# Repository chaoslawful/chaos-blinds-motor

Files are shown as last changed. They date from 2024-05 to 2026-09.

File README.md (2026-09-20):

# Chaos Blinds Motor

English | [中文](README-zh.md)

## Introduction

This project implements a blinds motor based on ESP8266 MCU, allowing users to manually control the blinds opening and closing using a universal infrared remote control or remotely via the HomeAssistant gateway. Compared to existing products on the market, this project has the following benefits:

* Low cost: The total cost of components plus the 3D-printed casing is less than 50 RMB, which is 1/4 to 1/5 of the price of commercial products.

* Completely open: The circuit, code, and casing models are all open source, and components can be purchased on the market. Users can freely modify and add new functions.

* Educational: The structure is simple, suitable for hands-on DIY activities with children.

## Hardware Structure

Component list:

* **Main control board**: `NodeMCU Lolin V3` (or other development boards of the same size with pin function compatibility)

* **Motor driver**: `DRV8833` module

* **Infrared receiver**: `HX1838`

* **DC motor**: Single-axis worm gear reduction motor with Hall encoder (preferably with metal gears)

The wiring diagram is as follows:

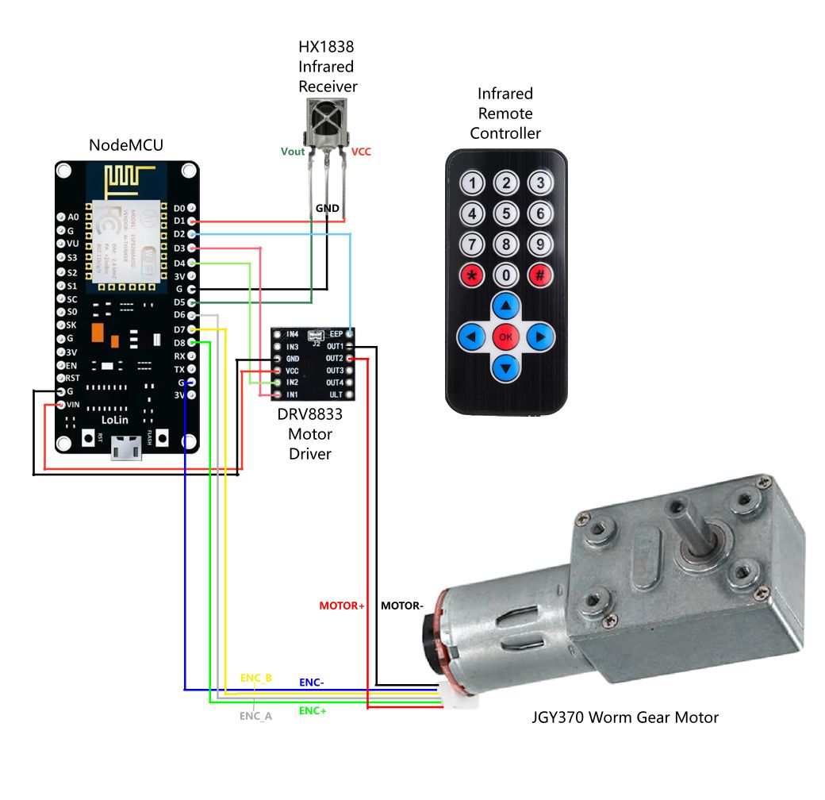
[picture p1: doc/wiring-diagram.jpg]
Wiring Diagram


## Firmware Compilation and Upload

The firmware is now the ESPHome reimplementation in `esphome/` (the legacy Arduino implementation has been removed from the working tree; see the git history if you need it). Refer to `esphome/README.md` for build, first-flash and OTA instructions.

## Make outer casing

When using FDM 3D printing, consider the following slicing parameters:

* Layer height: 0.12mm

* Number of walls: 6

* Sparse infill density: 25%

### Ball Chain Pulley

Open the [](./cad/ball-chain-pulley.step) file in your slicing software, split it into objects, and automatically arrange them for printing. Finally, use 4 **M3x12** screws to fix the upper and lower halves of the pulley together. If you need to add spacers, use 4 **M3x16** screws to fix the upper and lower halves of the pulley and the spacers together.

The reference layout in the slicing software is as follows:

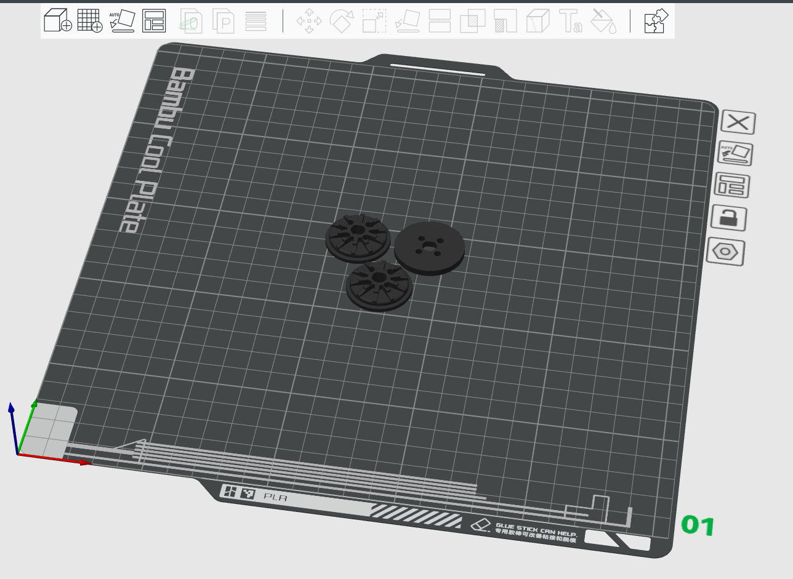
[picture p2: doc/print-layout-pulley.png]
Reference layout for pulley


#### Blinds Motor Casing

Open the [](./cad/chaos-blinds-motor.step) file in your slicing software, split it into objects, and automatically arrange them for printing. Note that the locking pieces should be placed sideways and add a **5mm brim** to stabilize printing. After printing, glue the locking pieces and sliders together with glue to form a complete back plate fixing piece.

The reference layout in the slicing software is as follows:

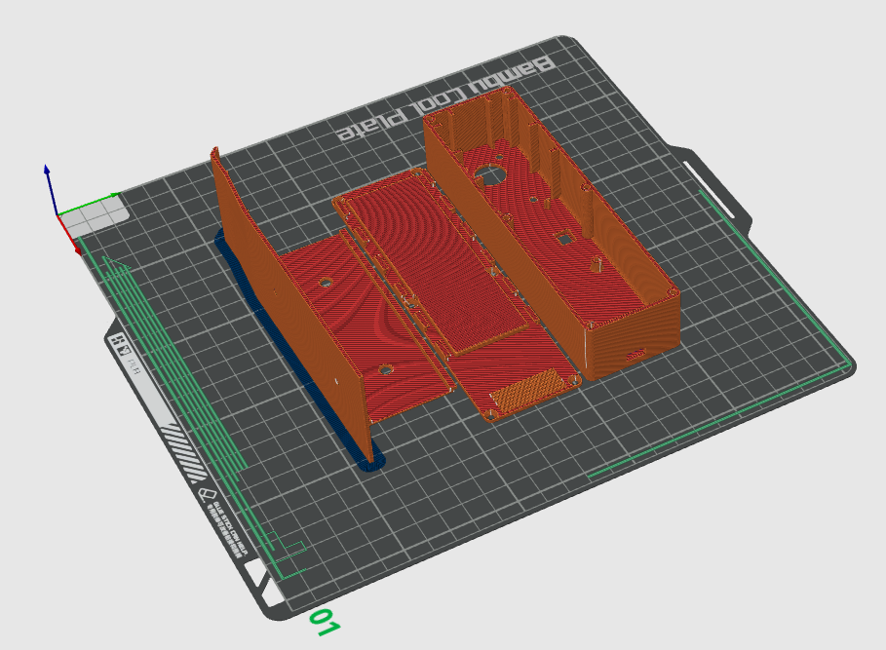
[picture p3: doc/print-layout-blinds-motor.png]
Reference layout for blinds motor


## Assembly

1. Before assembly, connect various components with DuPont wires according to the wiring diagram. Test the functionality before disassembling and continuing with the assembly.

2. Secure the NodeMCU board with 4 **M3x4** countersunk self-tapping screws, with the back facing up, inside the casing. The MicroUSB port should fit into the rectangular opening at the bottom.

3. Use hot glue to secure the DRV8833 module to the back of the NodeMCU near the MicroUSB port.

4. Use 4 **M3x6** countersunk screws to secure the reduction motor to the casing.

5. Connect various components with DuPont wires according to the wiring diagram and bundle them with plastic zip ties, making sure not to obstruct the rotation of the magnet ring of the Hall encoder.

6. Use 4 **M3x12** countersunk self-tapping screws to secure the back plate to the casing.

7. Install the ball chain pulley onto the motor shaft and hang the blinds ball chain. Find the appropriate installation position and angle to ensure that the chain is tensioned without entanglement and the blinds motor can slide freely into and out of the back plate fixing piece. Mark the appropriate position and angle.

8. Secure the back plate fixing piece at the marked position using expansion screws or 3M double-sided tape. Slip the ball chain onto the blinds motor pulley and insert the blinds motor into the back plate fixing piece.

9. Connect a **5~7.2V** external DC power supply to the MicroUSB port. The higher the voltage, the faster the blinds will rise and fall.

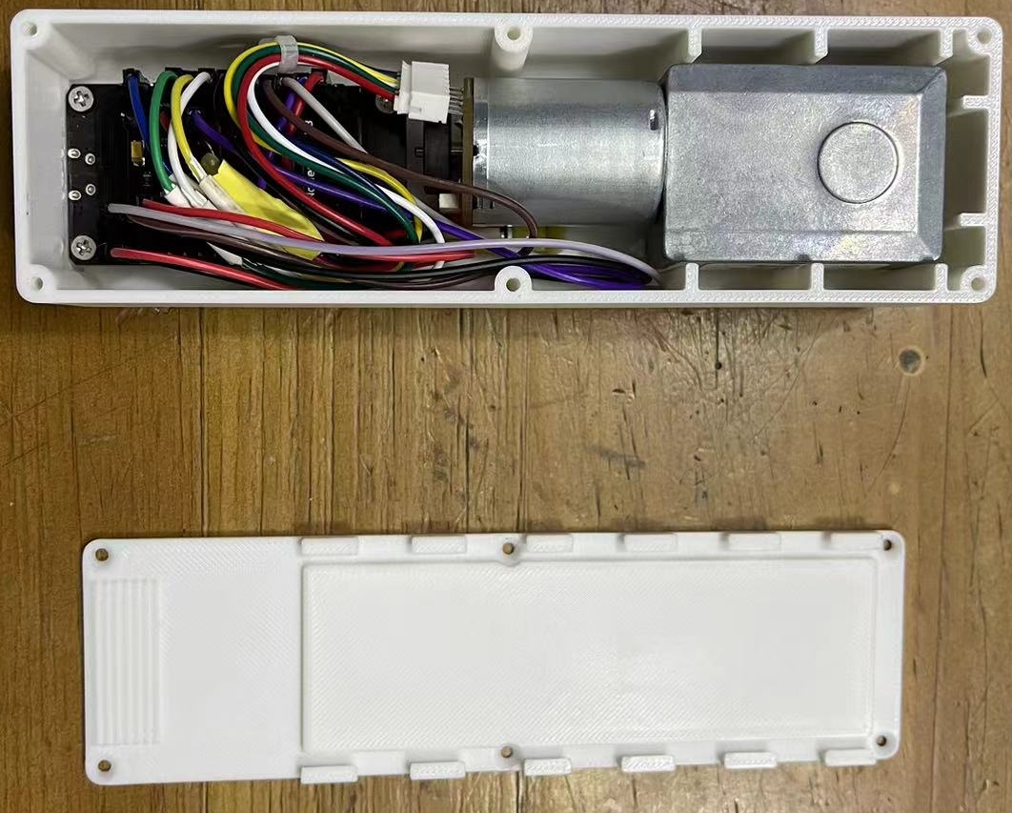
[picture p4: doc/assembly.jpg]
Assembly reference


## Configuration and Usage

1. **Network Configuration**: After the first power-up, wait for 5 seconds. Search for the hotspot named `ESP-xxxxxx` on your phone and connect to it. The wireless and MQTT configuration interface will automatically pop up. Fill in the wireless SSID and password, MQTT service address, port, login username, and password, and then save and close. At this point, the blinds motor will automatically connect to your wireless hotspot and the corresponding HomeAssistant (HA) service.

   * The MQTT-related parameters depend on your HA service configuration. Please search online for how to configure the HA service in the local network and allow external devices to access the HA service through MQTT.

2. **Travel Calibration**: The left and right buttons on the remote control can forcibly control the motor movement. Normally, the left button raises and the right button lowers the blinds. Press the `OK` button to stop the motor. If the movement direction is reversed, sequentially press the `0` and `#` buttons on the remote control to set the motor to reverse movement. Control the motor to move the blinds to the fully open position. Press the `0` and `1` buttons sequentially to save the fully open position. Then move the blinds to the fully closed position. Press the `0` and `3` buttons sequentially to save the fully closed position. The travel calibration is now complete. If necessary, press the `0` and `2` buttons sequentially to clear the calibrated travel and reset the current motor position to the initial position.

3. **Usage**:
   * Remote control up button: Fully open the blinds.
   * Remote control down button: Fully close the blinds.
   * Remote control `OK` button: Stop the motor.
   * After successfully connecting to the HA service, you can control it through the web or mobile app in the same way. You can also use automation rules in HA for scheduled blinds opening and closing.

## Acknowledgments

* [Parametric pulley generator for Aqara roller shade driver e1 by 2by2 - Thingiverse](https://www.thingiverse.com/thing:6116520)

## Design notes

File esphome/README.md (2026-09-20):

# 混沌猫升窗器 · ESPHome 版

原 Arduino 版（已从本仓库移除，历史提交中仍可查阅）的 ESPHome 重构实现，功能完全对齐，基础设施（WiFi/OTA/日志/持久化/看门狗）全部由 ESPHome 托管。

## 目录结构

```
esphome/
├─ chaos-blinds-motor.yaml    # 主配置（引脚/WiFi/API/OTA/红外状态机/HA 实体）
├─ secrets.yaml               # 凭据（首次使用前填写）
└─ components/
   └─ motor_pid/              # 自写外部组件：位置闭环 PID 电机 Cover
      ├─ __init__.py          # ESPHome 代码生成与配置校验
      ├─ motor_pid.h
      └─ motor_pid.cpp        # 控制环（移植自原版 MotorService）
```

## 快速开始

```bash
pip install esphome
cd esphome

# 1. 填写 secrets.yaml（api_encryption_key 用 openssl rand -base64 32 生成）

# 2. 校验配置
esphome config chaos-blinds-motor.yaml

# 3. 烧录（二选一，见下）
esphome run chaos-blinds-motor.yaml
```

### 首次烧录方式

**方式 A：免拆机 OTA 迁移（推荐，设备仍在运行旧 Arduino 固件时）**

ESPHome 的 OTA 与旧固件的 ArduinoOTA 使用同一协议（ESP8266 TCP 8266 端口），可直接无线推送，无需 USB：

1. 先把 `secrets.yaml` 的 `ota_password` 填为 `chaos123456`（**必须与旧固件当前密码一致**，OTA 校验的是设备上正在运行的固件的密码）；
2. 指定设备 IP 推送（旧固件 mDNS 主机名与新版不同，不要依赖自动发现）：

```bash
esphome run chaos-blinds-motor.yaml --device <设备IP>
```

3. 首次刷入成功后，之后的 OTA 密码以 `secrets.yaml` 为准，可改新密码。

**方式 B：USB 烧录**

`esphome run chaos-blinds-motor.yaml` 即可（自动检测串口）。

烧录前建议先用 `esptool.py read_flash` 备份原版固件，以便随时回退（Arduino 版仓库保留即可）。

## 标定流程（与原版一致）

红外遥控器操作（所有标定键需先按 `0` 且电机位置不动）：

| 按键 | 功能 |
|---|---|
| ← / → | 手动升起 / 放下（全速） |
| OK | 停止 |
| ↑ / ↓ | 自动运行至全开 / 全关 |
| 0,1 | 标定当前位置为全开点 |
| 0,3 | 标定当前位置为全关点 |
| 0,2 | 清除标定并归零编码器 |
| 0,# | 切换电机转向 |
| 0,4 | 手动对时（本版 SNTP 自动对时，此键仅打日志） |

Home Assistant 侧提供等价能力：原生 **Cover 实体**（开/关/停/任意位置百分比 + 位置反馈）、标定按钮三个、手动点动按钮三个（Jog Open / Jog Close / Jog Stop，与红外 ← → OK 等价，全速运转直到判稳停、60s 硬超时或手动停止）、转向反转开关、WiFi 信号/运行时长传感器。

## 与原版差异（有意为之的改动）

| 项 | 原版 | 本版 | 原因 |
|----|---|---|---|
| HA 通道 | MQTT + ArduinoHA 三按钮 | 原生 API（加密）+ Cover 实体 | 修复凭据泄露（R1），体验升级 |
| 清 WiFi 配 | RESET 后按 FLASH 键（占用 D3） | 回退 AP + captive_portal | 修复 D3 引脚冲突（R3） |
| 配置持久化 | LittleFS 裸 JSON 写 | ESPHome preferences（原子 + CRC） | 修复掉电丢标定（R4） |
| 运动超时 | 无 | `max_run_time` 默认 60s 硬停机 | 新增失控兜底（R5） |
| 手动停止后 | 不保存位置 | 保存位置 | 更稳妥 |
| PWM 频率 | 128Hz（可闻啸叫） | 默认 20kHz（YAML 可改回） | 体验改进（R14） |
| 主频 | 160MHz 超频 | 80MHz | ESPHome 不支持该配置；5ms 环裕量充足 |
| Web 日志 | 8080 无鉴权、含明文密码 | 80 端口带鉴权 | 安全 |
| 电池电压 | pins.h 预留死代码 | 不移植（A0 无分压电路，无实际用途） | 用户确认移除 |

## PID 调试

固件已编译进 VERBOSE 级日志（`logger.level: VERBOSE` + `initial_level: INFO`），日常运行零开销。调试时无需改配置、无需重刷：

- **Web 控制台**：日志级别下拉框切到 `VERBOSE`；
- 或 `logger.set_level` 动作 / `esphome logs` 切换。

随即输出 Teleplot 格式的 `>pos:` / `>speed:` / `>pwm:` 数据流，与原版串口调试方式一致；调完切回 `INFO` 即可。

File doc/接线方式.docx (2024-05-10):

#### 接线方式

HX1838: VCC ---- NodeMCU: D1

HX1838: GND ---- NodeMCU: 紧挨着 D5 的 GND

HX1838: VOUT ---- NodeMCU: D5

DRV8833: EEP ---- NodeMCU: D2

DRV8833: IN1 ---- NodeMCU: D3

DRV8833: IN2 ---- NodeMCU: D4

DRV8833: VCC ---- NodeMCU: Vin

DRV8833: GND ---- NodeMCU: 紧挨着Vin的GND

DRV8833: OUT1 ---- 减速电机: MOTOR-（黑）

DRV8833: OUT2 ---- 减速电机: MOTOR+（红）

减速电机: ENC_A（白）---- NodeMCU: D6

减速电机: ENC_B（黄）---- NodeMCU: D7

减速电机: ENC+（绿）---- NodeMCU: D8

减速电机: ENC-（蓝）---- NodeMCU: 紧挨着3.3V的GND

#### HX1838 引脚图

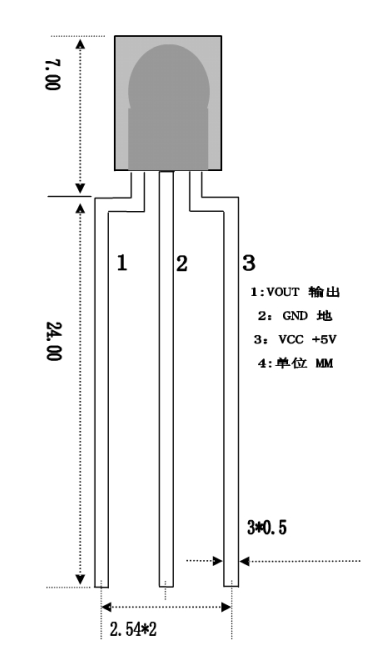
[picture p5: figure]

#### DRV8833 引脚图

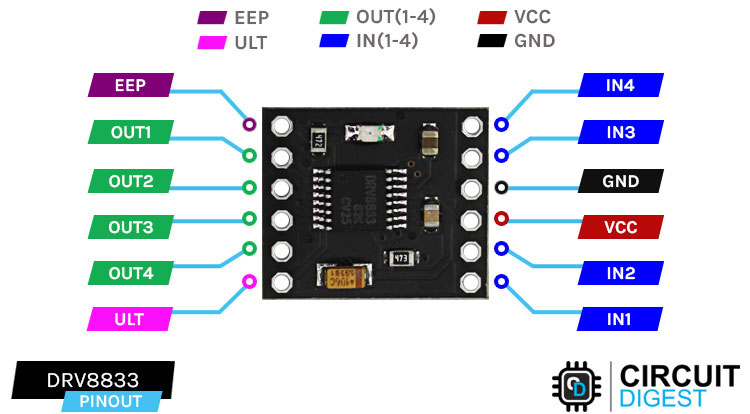
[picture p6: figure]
Interfacing DRV8833 Dual Motor Driver Module with Arduino

#### NodeMCU 引脚图

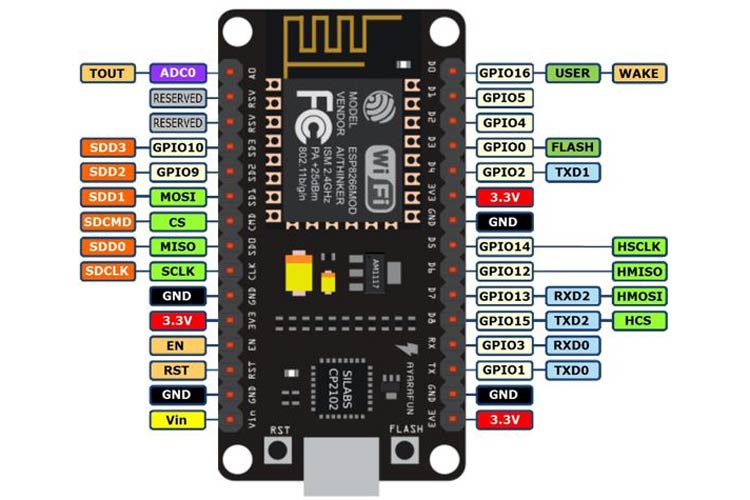
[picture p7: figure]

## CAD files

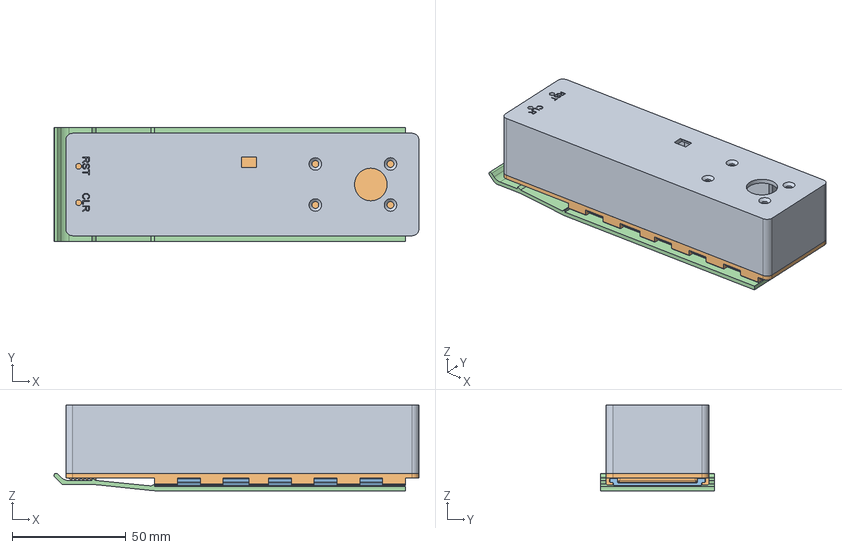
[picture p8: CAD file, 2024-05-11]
cad/chaos-blinds-motor.step
160.2 x 50.0 x 37.6 mm
外壳
外壳滑动背板
滑片
锁紧片

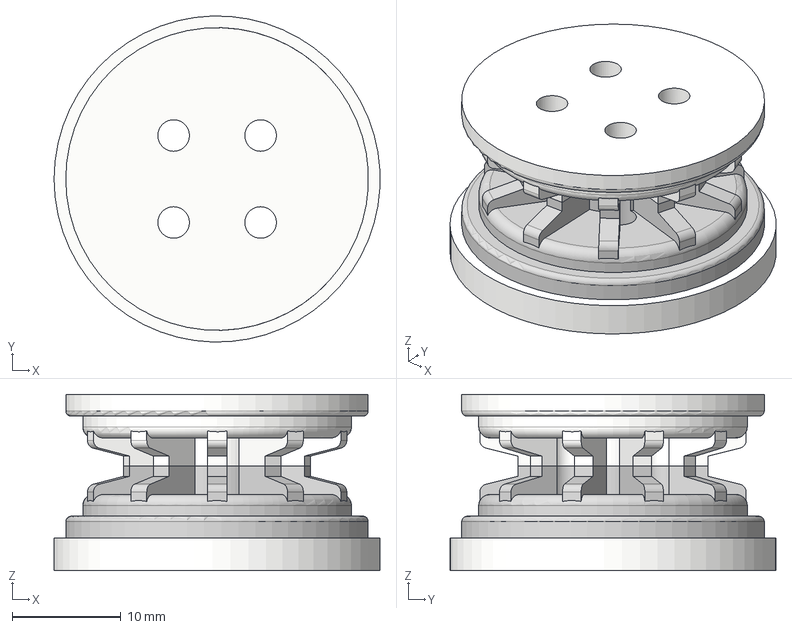
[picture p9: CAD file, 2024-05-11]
cad/ball-chain-pulley.step
30.0 x 30.0 x 16.2 mm
TopHalf
BottomHalf
Spacer

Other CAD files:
cad/ball-chain-pulley.f3d
cad/chaos-blinds-motor.f3d

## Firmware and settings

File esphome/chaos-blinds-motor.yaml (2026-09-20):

# ================================================================
# 混沌猫升窗器 —— ESPHome 重构版
# 目标硬件：NodeMCU Lolin V3 (ESP8266) + DRV8833 + 370 蜗轮减速电机
#           （霍尔编码器 12PPR）+ HX1838 红外接收 + NEC 17 键遥控器
# 功能与 Arduino 版完全对齐，差异详见 README.md「与原版差异」一节
# ================================================================

esphome:
  name: chaos-blinds-motor
  friendly_name: 混沌猫升窗器
  comment: "基于 ESPHome 的百叶窗自动升窗器"
  project:
    name: chaos.blinds_motor
    version: "2.0.0"
  on_boot:
    # 尽早使能编码器与红外接收头电源（对应原版构造函数中的 digitalWrite HIGH）
    priority: 600
    then:
      - lambda: |-
          pinMode(${enc_pwr_pin}, OUTPUT);
          digitalWrite(${enc_pwr_pin}, HIGH);
          pinMode(${ir_pwr_pin}, OUTPUT);
          digitalWrite(${ir_pwr_pin}, HIGH);

# ----------------------------------------------------------------
# 引脚定义（与 src/config/pins.h 一一对应）
# 注意：D3 在原版中被「FLASH 清配按钮」与「电机 IN1」双重占用（缺陷 R3），
#       本版清配功能由 captive_portal 取代，D3 独占电机 PWM。
# ----------------------------------------------------------------
substitutions:
  drv_in1_pin: D3    # DRV8833 输入 1（PWM）
  drv_in2_pin: D4    # DRV8833 输入 2（PWM）
  drv_eep_pin: D2    # DRV8833 使能（高电平工作，低电平休眠）
  enc_a_pin: D6      # 编码器 A 相
  enc_b_pin: D7      # 编码器 B 相
  enc_pwr_pin: D8    # 编码器电源
  ir_pin: D5         # 红外接收数据
  ir_pwr_pin: D1     # 红外接收电源

esp8266:
  board: nodemcuv2
  # 注：原版超频 160MHz 的配置 ESPHome 不支持；80MHz 下 5ms PID 环裕量充足，
  #     实测 loop 耗时远低于采样周期，无功能影响。

# WiFi：失败自动重连；连不上时开启回退 AP + 配网门户（取代 WiFiManager）
wifi:
  ssid: !secret wifi_ssid
  password: !secret wifi_password
  fast_connect: on
  ap:
    ssid: "Blinds-Motor Fallback"
    password: !secret ap_password

captive_portal:

# HA 原生 API（加密；取代原版的 MQTT + ArduinoHA 通道）
api:
  encryption:
    key: !secret api_encryption_key
  reboot_timeout: 5min

# OTA：改用 Noise 加密（继承 api 的 encryption key 认证上传者），
# 替代初始迁移期临时使用的 password（迁移已完成，密码不再需要）
ota:
  - platform: esphome
    encryption:

# 日志：编译期全局级别设为 VERBOSE（把组件内 Teleplot 位置/速度/PWM 调试输出编进固件），
# 但 initial_level 保持 INFO 不影响日常性能；
# 调试 PID 时无需重刷固件，网页控制台下拉框或 logger.set_level 直接切到 VERBOSE 即可
logger:
  level: VERBOSE
  initial_level: INFO
  logs:
    wifi: ERROR
    web_server: ERROR
  baud_rate: 115200

# Web 控制台（带鉴权；取代原版 8080 端口的无鉴权日志页，修复凭据泄露）
web_server:
  port: 80
  auth:
    type: digest
    username: !secret web_user
    password: !secret web_password

# 时间同步：SNTP 非阻塞（取代原版每小时阻塞式 NTP）
time:
  - platform: sntp
    id: ntp_time
    timezone: CST-8
    servers:
      - cn.pool.ntp.org
      - ntp.aliyun.com
    on_time_sync:
      - logger.log: "Time synchronized via SNTP"

# 本地外部组件：位置闭环 PID 电机 Cover
external_components:
  - source:
      type: local
      path: components

# ================================================================
# 电机 Cover（自写组件 motor_pid，HA 中呈现为原生 Cover 实体，
# 支持 open / close / stop / set_position 与位置百分比反馈）
# 注意：必须以 cover 平台方式注册，顶层 motor_pid: 域不会把 cover
# 组件源码加入编译（USE_COVER 已定义但 cover.h 缺失，编译失败）
# ================================================================
cover:
  - platform: motor_pid
    id: motor_cover
    name: "百叶窗"
    in1_pin: ${drv_in1_pin}
    in2_pin: ${drv_in2_pin}
    sleep_pin: ${drv_eep_pin}
    encoder_a_pin: ${enc_a_pin}
    encoder_b_pin: ${enc_b_pin}
    # 控制参数与原版 src/service/motor.h 默认值一致
    kp: 2.0
    ki: 0.2
    kd: 0.12
    sample_time: 5ms
    stable_samples: 20
    stable_window: 50ms
    abs_tolerance: 80.0
    rel_tolerance: 0.01
    max_run_time: 60s        # 新增安全兜底：运动硬超时
    pwm_frequency: 20kHz     # 原版 128Hz 有可闻啸叫；要完全一致可改回 128Hz
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

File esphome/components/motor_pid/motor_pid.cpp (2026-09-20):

#include "motor_pid.h"
#include "esphome/core/log.h"
#include "esphome/core/helpers.h"
#include <cmath>

namespace esphome {
namespace motor_pid {

static const int PWM_RANGE = 255;  // 与原版一致：analogWriteRange(255)

// ------------------------------------------------------------------
// 生命周期
// ------------------------------------------------------------------

void MotorPIDCover::setup() {
  // DRV8833 引脚初始化：默认停机 + 驱动模块休眠（直接操作原始 GPIO，与原版一致）
  pinMode(in1_, OUTPUT);
  pinMode(in2_, OUTPUT);
  pinMode(sleep_, OUTPUT);

  analogWriteRange(PWM_RANGE);
  analogWriteFreq(pwm_freq_);
  analogWrite(in1_, 0);
  analogWrite(in2_, 0);
  digitalWrite(sleep_, LOW);

  // 编码器（PJRC，中断驱动）
  encoder_ = new Encoder(enc_a_, enc_b_);

  // 速度 EMA 滤波系数：α = 1 - e^(-T/τ)，τ = 1/(2π·fc)，T = 10ms（与原版一致）
  float tau = 1.0f / (2.0f * PI * speed_cutoff_hz_);
  speed_alpha_ = 1.0f - expf(-0.010f / tau);

  // 恢复持久化状态（标定点 + 停机位置 + 转向）
  MotorState st;
  int32_t restore_pos = 0;
  if (load_state_(st)) {
    full_open_ = st.full_open;
    full_close_ = st.full_close;
    reversed_ = st.reversed != 0;
    restore_pos = st.current;
    ESP_LOGI(TAG, "Restored: open=%d close=%d pos=%d reversed=%d", full_open_, full_close_, restore_pos,
             reversed_);
  } else {
    ESP_LOGW(TAG, "No valid calibration state found, using defaults (0/0/0)");
  }
  encoder_->write(restore_pos);

  publish_position_();
}

void MotorPIDCover::dump_config() {
  ESP_LOGCONFIG(TAG, "Motor PID Cover:");
  ESP_LOGCONFIG(TAG, "  PID: kp=%.3f ki=%.3f kd=%.3f sample=%ums", kp_, ki_, kd_, sample_time_ms_);
  ESP_LOGCONFIG(TAG, "  Stable: %d samples x %ums, tol abs=%.1f rel=%.3f", stable_samples_, stable_window_ms_,
                abs_tol_, rel_tol_);
  ESP_LOGCONFIG(TAG, "  Max run time: %ums, PWM freq: %uHz", max_run_time_ms_, pwm_freq_);
  ESP_LOGCONFIG(TAG, "  Calibration: open=%d close=%d reversed=%d", full_open_, full_close_, reversed_);
}

void MotorPIDCover::loop() {
  uint32_t now = millis();
  measure_speed_(now);

  if (pid_active_ && now - last_pid_ms_ >= sample_time_ms_) {
    last_pid_ms_ = now;
    run_pid_(now);
  }

  check_stable_(now);

  // 运动硬超时（新增安全兜底）：无论何种原因，超时无条件停机
  if (moving_ && now - move_start_ms_ > max_run_time_ms_) {
    ESP_LOGW(TAG, "SAFETY: max run time (%ums) exceeded, forcing stop", max_run_time_ms_);
    finish_move_(false);
  }

  // 运动中按 500ms 节流发布位置百分比
  if (moving_ && now - last_publish_ms_ >= 500) {
    last_publish_ms_ = now;
    publish_position_();
  }
}

// ------------------------------------------------------------------
// Cover 接口
// ------------------------------------------------------------------

cover::CoverTraits MotorPIDCover::get_traits() {
  auto traits = cover::CoverTraits();
  traits.set_supports_stop(true);
  traits.set_supports_position(true);
  return traits;
}

void MotorPIDCover::control(const cover::CoverCall &call) {
  if (call.get_stop()) {
    ESP_LOGI(TAG, "HA command: stop");
    stop_motor();
    return;
  }
  if (call.get_position().has_value()) {
    float pos = *call.get_position();
    // HA Cover 语义：1.0 = 全开，0.0 = 全关
    long target = full_close_ + lroundf((float) (full_open_ - full_close_) * pos);
    ESP_LOGI(TAG, "HA command: position %.2f -> %ld pulses", pos, target);
    goto_pos_(target);
  }
}

void MotorPIDCover::publish_position_() {
  float denom = (float) (full_open_ - full_close_);
  if (denom != 0.0f) {
    float p = (float) (get_pos_pulse() - full_close_) / denom;
    this->position = clamp(p, 0.0f, 1.0f);
  }
  if (!moving_) {
    this->current_operation = cover::COVER_OPERATION_IDLE;
  }
  this->publish_state();
}

// ------------------------------------------------------------------
// 业务接口
// ------------------------------------------------------------------

long MotorPIDCover::get_pos_pulse() {
  long val = encoder_->read();
  return reversed_ ? -val : val;
}

void MotorPIDCover::goto_open() {
  ESP_LOGI(TAG, "Command: auto open -> %d", full_open_);
  goto_pos_(full_open_);
}

void MotorPIDCover::goto_close() {
  ESP_LOGI(TAG, "Command: auto close -> %d", full_close_);
  goto_pos_(full_close_);
}

void MotorPIDCover::manual_open() {
  ESP_LOGI(TAG, "Command: manual open (CCW)");
  pid_active_ = false;
  integral_ = 0.0;
  moving_ = true;
  move_start_ms_ = millis();
  good_samples_ = 0;
  stable_last_pos_ = get_pos_pulse();
  stable_last_ms_ = millis();
  this->current_operation = cover::COVER_OPERATION_OPENING;
  this->publish_state();
  motor_backward_(PWM_RANGE);
}

void MotorPIDCover::manual_close() {
  ESP_LOGI(TAG, "Command: manual close (CW)");
  pid_active_ = false;
  integral_ = 0.0;
  moving_ = true;
  move_start_ms_ = millis();
  good_samples_ = 0;
  stable_last_pos_ = get_pos_pulse();
  stable_last_ms_ = millis();
  this->current_operation = cover::COVER_OPERATION_CLOSING;
  this->publish_state();
  motor_forward_(PWM_RANGE);
}

void MotorPIDCover::stop_motor() {
  ESP_LOGI(TAG, "Command: stop");
  finish_move_(true);
}

void MotorPIDCover::toggle_reverse() {
  reversed_ = !reversed_;
  ESP_LOGI(TAG, "Motor direction: %s", reversed_ ? "reversed" : "normal");
  save_state_();
}

void MotorPIDCover::set_reverse_persist(bool rev) {
  if (reversed_ == rev)
    return;
  reversed_ = rev;
  ESP_LOGI(TAG, "Motor direction: %s", reversed_ ? "reversed" : "normal");
  save_state_();
}

void MotorPIDCover::mark_open_here() {
  full_open_ = get_pos_pulse();
  ESP_LOGI(TAG, "Marked full open position: %d", full_open_);
  save_state_();
  publish_position_();
}

void MotorPIDCover::mark_close_here() {
  full_close_ = get_pos_pulse();
  ESP_LOGI(TAG, "Marked full close position: %d", full_close_);
  save_state_();
  publish_position_();
}

void MotorPIDCover::clear_calibration() {
  ESP_LOGI(TAG, "Clear calibration");
  stop_motor();
  full_open_ = 0;
  full_close_ = 0;
  encoder_->write(0);
  save_state_();
  publish_position_();
}

// ------------------------------------------------------------------
// 控制环（移植自 MotorService）
// ------------------------------------------------------------------
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

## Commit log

2024-05-06 change calibration keys to 0/1, 0/2 and 0/3 sequence
2024-05-08 fixed motor position reset function
2024-05-10 change model type shown in HA; increased motor's manually control speed; add assembling document
2024-05-11 add CAD design files
    [拉珠滚轮 v9.f3d, 拉珠滚轮 v9.step, 混沌猫升窗器 v28.f3d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]
2024-05-11 remove unused battery related code
2024-05-11 restore ArduinoOTA settings
2024-05-11 add wiring diagram
2024-05-11 update CAD files
    [ball-chain-pulley.f3d, ball-chain-pulley.step, chaos-blinds-motor.f3d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]
2024-05-11 add motor reverse toggle function
2024-11-28 fixed timestamp printf bug and add force ntp sync key sequence
2024-11-30 add motor state saved log
2026-03-04 fix retain settings for close and stop buttons, improve motor speed calculation, enhance NTP sync error handling, and update OTA progress logging
2026-09-20 fix: mount LittleFS once in setup, force brake on stop, speed/NTP robustness
    - main: 文件系统改为启动时统一挂载一次，去掉各服务重复 begin
    - motor: stop() 无论是否到达判稳都强制刹车；编码器无位移时速度直接归零，避免 EMA 残留
    - ntp: sync_time_ 返回同步结果，校验时间有效性（>2024-01-01），失败回退默认起始时间
    - wireless: 移除重复的 LittleFS 挂载
    - README: 注明需 NEC 协议 17 键遥控器
2026-09-20 refactor: move legacy Arduino/PlatformIO firmware into arduino/ subdirectory
2026-09-20 feat: ESPHome reimplementation of chaos-blinds-motor with motor_pid component
    - esphome/components/motor_pid/: 自定义外部组件，完整移植 PID 位置环
    （PID_v1 语义）、判稳/堵转保护、编码器判向、EMA 测速、preferences
    原子持久化，新增 max_run_time 硬超时兜底失控场景
    - esphome/chaos-blinds-motor.yaml: WiFi/加密 API/OTA/SNTP/Web 鉴权/
    captive portal/红外 NEC 状态机全键映射（含 0+x 组合键协议）/
    标定按钮/转向开关/PID 参数在线调节；logger 编译 VERBOSE、
    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
    [chaos-blinds-motor.yaml]
2026-09-20 docs: update build instructions for arduino/ and esphome/ layout
2026-09-20 docs: add ArduinoOTA migration flash path and update PID debug notes in esphome README
2026-09-20 chore: stop tracking esphome/secrets.yaml, ignore it and __pycache__
    secrets.yaml 已填真实凭据，继续跟踪有误入库风险；历史版本仅含模板占位符。
    本地文件保留不受影响。
2026-09-20 fix: disambiguate calibration button IDs, use digest auth for web_server
    纯中文按钮名转 ASCII ID 时互相撞名（标定全开/全关位置），用 object_id
    显式区分；web_server auth 改用 digest 消除 basic 明文传输弃用警告。
    [chaos-blinds-motor.yaml]
2026-09-20 fix: register motor_pid as cover platform instead of top-level domain
    [chaos-blinds-motor.yaml]
2026-09-20 fix: move motor_pid platform registration to cover.py per component layout convention
2026-09-20 fix: use raw GPIO numbers instead of GPIOPin API in motor_pid component
    新版 ESPHome HAL 的 GPIOPin 无 get_pin() 公开接口；改为 cover.py 传
    引脚编号、C++ 直接 pinMode/analogWrite/digitalWrite 操作（与原版
    Arduino 代码同风格）。顺带修正 load_state_ 声明与实现签名不一致。
    [motor_pid.cpp]
2026-09-20 fix: require_waveform() for ESPHome 2026.1+ ESP8266 PWM exclusion
2026-09-20 feat: switch OTA to Noise encryption inheriting API key (migration complete)
    [chaos-blinds-motor.yaml]
2026-09-20 chore: track esphome/.gitignore generated by esphome tooling
2026-09-20 feat: add logger select entity for web/HA runtime log level switching
    [chaos-blinds-motor.yaml]
2026-09-20 fix: cover operation direction was inverted when full_open < full_close
    Direction judged by target vs current position (or vs full_close anchor)
    breaks when the open end has a numerically smaller pulse count than the
    close end (open=-6862 < close=2295 here): opening was reported as
    CLOSING, flipping HA icon/text. Now polarity-agnostic: whichever
    calibration endpoint the target is closer to decides the operation.
    [motor_pid.cpp]
2026-09-20 fix: IR receiver polarity and raise key debounce to 200ms
    - remote_receiver pin inverted:false -> true: HX1838 idles high and
    pulls low on carrier; without inversion decoding fails silently
    (no logs even at VERBOSE). Verified: NEC keys decode and drive the
    motor after the change.
    - Debounce 100ms -> 200ms: NEC long-press repeat frames arrive every
    ~110ms; 100ms window let them through, so one press of key 3 fired
    the calibrate action three times.
    [chaos-blinds-motor.yaml]
2026-09-20 docs: document jog buttons for HA-side manual motor control
    Three template buttons (Jog Open / Jog Close / Jog Stop) equivalent to
    IR LEFT/RIGHT/OK, added in a previous YAML change; update README's
    HA capability list to match.
2026-09-20 refactor: remove legacy Arduino implementation, ESPHome is now the sole firmware
    The ESPHome reimplementation has been running on the physical device
    since 2026-09-20 with all features verified (cover control, IR remote,
    calibration, jog buttons). Remove the legacy Arduino tree and the
    one-off migration assessment doc; both remain in git history.
    - delete arduino/ (sources, platformio.ini, READMEs)
    - delete doc/架构评估与ESPHome重构方案.md (migration finished)
    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
